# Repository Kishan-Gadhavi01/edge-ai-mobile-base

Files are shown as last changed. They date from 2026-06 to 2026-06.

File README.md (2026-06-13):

# Edge AI Mobile Base: VIO SLAM Subsystem

🟢 **System Status:** Active R&D / Phase 2 (Perception Optimization)

**The foundational mobility and spatial awareness module for an upcoming Embodied AI Mobile Manipulator. This independent subsystem utilizes ROS 2 Humble, NVIDIA Jetson, and an OAK-D Lite to achieve robust encoderless Visual-Inertial Odometry (VIO) and map generation.**

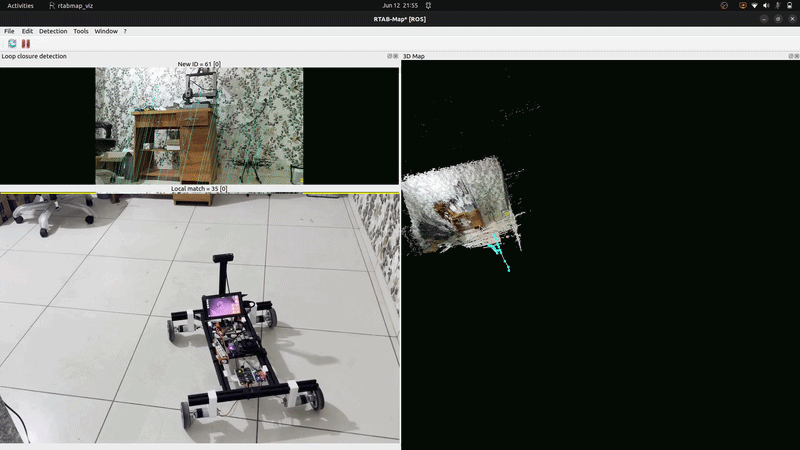
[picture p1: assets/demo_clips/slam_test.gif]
Chassis VIO SLAM Tracking


## 🧠 Modular Architecture Context

This repository houses the **Mobility and Perception Subsystem**. Operating as a fully independent Autonomous Mobile Robot (AMR) base, it is engineered with a strict **Distributed Middleware Architecture** to isolate real-time motor actuation from heavy spatial AI processing:

* **Actuation Layer (Low-Level):** An ESP32 microcontroller acting as a Hardware Abstraction Layer (HAL). It handles deterministic differential mixing and interfaces directly with Cytron motor drivers via a high-speed wireless UDP bridge.
* **Perception Layer (High-Level):** An NVIDIA edge compute node (Jetson) processing spatial depth maps and executing Visual-Inertial Odometry via ROS 2, eliminating the reliance on standard hardware wheel odometry.

---

## 📂 Repository Structure

```text
edge-ai-mobile-base/
├── cad/                        # 3D printable STL files and mechanical assembly diagrams
├── bom/
│   └── bom.md    # Component specs (motors, drivers, compute units)
├── esp_firmware/               # MicroPython code executed directly on the ESP32 HAL
│   ├── phase1_ap_mode/         # Standalone Wi-Fi Access Point execution script
│     └── main.py
│   └── phase2_client_mode/     # Distributed ROS 2 Subnet network execution script
│     └── main.py
├── host_controller/            # Python drive scripts executed on the Ubuntu Host Laptop
│   ├── phase1_manual/   
|     └──  robo_drive.py    
│   └── phase2_teleop/          # Routed subnet teleop mixing script (Subnet Client)
|     └── control.py    
├── ros2_nodes/                 # Perception stack executed directly on the NVIDIA Jetson
│   └── salm_ready.launch.py    # Custom VIO & RTAB-Map spatial mapping sequence
└── README.md                   # System overview & Deployment guide

```

---

## 🚀 Development Phases

### Phase 1: Hardware & Baseline Actuation - *Completed*

The foundational cycle focused entirely on verifying the physical chassis and ensuring deterministic, low-latency control before introducing AI overhead.

* **Mechanical & Electrical:** Designed custom 3D-printed mounting brackets for the Jetson and OAK-D. Integrated 12V motors and Cytron dual-channel drivers. *(See `/cad/` and `/bom/`)*
* **Wireless Teleoperation:** Engineered a high-speed MicroPython UDP server on the ESP32.
* **Kinematic Mixing:** Implemented a host-side teleoperation script to map standard Xbox controller axes into calculated differential PWM limits with strict deadzone filtering and emergency stop fallbacks.

### Phase 2: Embodied AI & Perception Integration - *Current*

Transitioning control from manual UDP teleoperation to an autonomous, middleware-driven ecosystem.

* **Middleware Integration:** Deployed ROS 2 Humble on the NVIDIA Jetson edge compute node.
* **Encoderless VIO SLAM:** Replaced physical wheel odometry with RTAB-Map's `rgbd_odometry` using the OAK-D Lite depth stream and internal IMU.
* **SLAM Resiliency Tuning:** Implemented custom parameter overrides (`Odom/GuessMotion: 'true'`, `Odom/ResetCountdown: '0'`) allowing the localization engine to predictive-coast during rapid yaw rotations to survive visual motion blur.
* **System-Level Optimization:** Tuned the Linux network kernel (`sysctl`) to expand packet fragmentation thresholds, stabilizing high-bandwidth point-cloud transmission.

---

## 🛠️ System Deployment & Replication Guide

Due to the distributed nature of this platform, setup and execution are split across the **ESP32 (Hardware Abstraction Layer)**, the **NVIDIA Jetson (Edge Node)**, and the **Ubuntu Host Laptop (Teleop & Visualization)**.

### Track 0: Actuation Firmware Installation (ESP32)

Before the AI middleware can communicate with the physical chassis, the ESP32 must be flashed with the correct network and kinematics firmware using the **Thonny IDE**.

1. **Select Operational Mode:**
* **Phase 1 (Standalone AP):** Use `esp_firmware/phase1_ap_mode/main.py`. The ESP32 hosts its own isolated Wi-Fi network. Best for raw teleop testing without a router.
* **Phase 2 (Subnet Client):** Use `esp_firmware/phase2_client_mode/main.py`. The ESP32 connects to your shared subnet (e.g., mobile hotspot) alongside the Jetson. **This is required for ROS 2 SLAM.**

2. **Configure Network:** Open the selected `main.py` in Thonny. If using Phase 2, update the hardcoded `SSID` and `PASSWORD` to match your host network.
3. **Flash:** Connect the ESP32 via USB, save `main.py` directly to the MicroPython device, and power cycle the chassis. The onboard LED will turn solid once the network and UDP listening socket (Port `12345`) are established.

---

### Track A: NVIDIA Jetson Setup (Perception Node)

**1. Base Dependencies & ROS 2 DepthAI Drivers**

```bash
sudo apt update && sudo apt upgrade -y
sudo apt install -y build-essential python3-dev htop nvtop gedit
sudo apt install -y libyaml-cpp-dev libarchive-dev libbz2-dev zlib1g-dev libcurl4-openssl-dev libprotobuf-dev protobuf-compiler liblzma-dev liblz4-dev
sudo apt install ros-humble-depthai-ros ros-humble-depth-image-proc ros-humble-rtabmap-launch -y
echo "source /opt/ros/humble/setup.bash" >> ~/.bashrc

```

**2. Deep Learning Environment Setup**
By default, NVIDIA Jetson platforms come pre-configured with TensorRT and CUDA bound to the native system Python.

*Standard Installation (Recommended):*
For the most stable experience, install the vision dependencies directly to your system:

```bash
pip3 install "numpy>=1.24,<2.0" opencv-python==4.9.0.80 tqdm pycuda

```

*Advanced Configuration (Conda Environments):*

> ⚠️ *Note: If you choose to use Miniconda to isolate your vision environment, Conda will break the native Jetson TensorRT and CUDA pathings. You must manually symlink the system libraries into your Conda environment.*

If you are using a Conda environment named `vision`, execute the following to restore hardware acceleration:

```bash
# 1. Install base dependencies inside Conda
conda install -c nvidia cuda-toolkit=12.4.1 cuda-version=12.4 cudnn -y
pip install "numpy>=1.24,<2.0" opencv-python==4.9.0.80 tqdm

# 2. Clean out conflicting conda libraries and link Jetson's native TensorRT bindings
rm -rf ~/miniconda3/envs/vision/lib/python3.10/site-packages/tensorrt*
rm -rf ~/miniconda3/envs/vision/lib/python3.10/site-packages/graphsurgeon*

ln -s /usr/lib/python3.10/dist-packages/tensorrt ~/miniconda3/envs/vision/lib/python3.10/site-packages/
ln -s /usr/lib/python3.10/dist-packages/graphsurgeon ~/miniconda3/envs/vision/lib/python3.10/site-packages/

# 3. Export explicit paths to your local CUDA compiler
export PATH=/usr/local/cuda-12.6/bin:$PATH
export LD_LIBRARY_PATH=/usr/lib/aarch64-linux-gnu:/usr/local/cuda-12.6/lib64:$LD_LIBRARY_PATH
export CUDA_ROOT=/usr/local/cuda-12.6

# 4. Force-compile PyCUDA from source against the localized compiler target
pip install pycuda --force-reinstall --no-binary :all:

```

**3. High-Throughput Kernel Tuning (Mandatory for Point Clouds)**
Execute this script to prevent ROS 2 node instability caused by UDP packet fragmentation over Wi-Fi:

```bash
sudo sysctl -w net.core.rmem_max=2147483647
sudo sysctl -w net.ipv4.ipfrag_time=3
sudo sysctl -w net.ipv4.ipfrag_high_thresh=134217728

```

---

### Track B: Ubuntu Host Laptop Setup (Teleop & Visualization)

**1. Teleoperation Environment**
Ensure an Xbox Controller is paired via Bluetooth to the laptop.

```bash
pip3 install pygame

```

**2. ROS 2 Visualization Dependencies**
The host laptop does not run the SLAM math, but it must be able to visualize the TF trees and point clouds generated by the Jetson.

```bash
sudo apt update
sudo apt install ros-humble-desktop ros-humble-rtabmap-viz -y
echo "source /opt/ros/humble/setup.bash" >> ~/.bashrc

```

---

## ⚡ Execution Sequence

To bring the entire Embodied AI platform online, execute these commands in the following sequence across your network:

**1. Initiate Teleoperation (Host Laptop)**

```bash
python3 host_controller/phase2_teleop/control.py

```

*(Use the Left Joystick to drive. The script manages raw kinematics and safety deadzones).*

**2. Initialize Vision Drivers (Jetson Terminal 1)**

```bash
ros2 launch depthai_ros_driver rgbd_pcl.launch.py 

```

**3. Launch Odometry & SLAM Engine (Jetson Terminal 2)**

```bash
rm -rf ~/.ros/rtabmap.db  # Clear stale mapping data
ros2 launch ros2_nodes/slam_ready.launch.py

```

**4. Remote Spatial Visualization (Host Laptop Terminal)**

```bash
ros2 run rtabmap_viz rtabmap_viz --ros-args -r rtabmap:=/rtabmap -r odom:=/rtabmap/odom

```

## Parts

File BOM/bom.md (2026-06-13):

### Bill of Materials (BOM)

| Phase | Qty | Component | Specification |
| --- | --- | --- | --- |
| **Phase 1** | 4 | Aluminum T-Slot Extrusions | 30x30 Profile 500mm |
| **Phase 1** | 4 | Cast Corner Brackets | EasyMech, for 30x30 Profile |
| **Phase 1** | 8 | Capped Allen Bolts & T-Nuts | M5, 11mm |
| **Phase 1** | 4 | Planetary Gear DC Motors | Pro-Range 12V, 185 RPM, 72.5 Ncm |
| **Phase 1** | 4 | Heavy Duty Disc Wheels | EasyMech 100mm, Gray |
| **Phase 1** | 4 | Anti-Slip Motor Couplings | EasyMech 8mm Internal Diameter (ID) |
| **Phase 1** | 1 | ESP32 Microcontroller | Hardware Abstraction Layer / Wi-Fi Subnet Client |
| **Phase 1** | 2 | Cytron MDD10A Motor Driver | Dual Channel Enhanced, 10A Continuous, 30A Peak |
| **Phase 1** | 1 | 3S LiPo Battery | Dedicated Drive Train Power |
| **Phase 1** | 1 | XL4015 DC-DC Stepdown Module | Adjustable Buck Converter (5A, 75W) with Digital Voltmeter (2x for pahse 2) |
| **Phase 1** | 2 | driver_support | 3D printed (petg prefferd) for cytron  |
| **Phase 1** | 4 | motor_mount | 3D printed (petg prefferd) |
| **Phase 1** | 1 | support | 3D printed (petg prefferd) |
| **Phase 2** | 1 | NVIDIA Jetson Orin Nano | Super Developer Kit (ROS 2 / SLAM Node) |
| **Phase 2** | 1 | Luxonis OAK-D Lite | Spatial Depth Camera with Autofocus |
| **Phase 2** | 1 | Waveshare HDMI LCD Display | 7-inch, 1024x600, Touch Screen with Case |
| **Phase 2** | 1 | 4S LiPo Battery | Pro-Range 14.8V, 5200mAh, 40C (Dedicated Compute Power) |
| **Phase 2** | 1 | XL4015 DC-DC Stepdown Module | Adjustable Buck Converter (5A, 75W) with Digital Voltmeter |

### Sites to procure items 
https://robu.in/

https://thinkrobotics.com/

https://tannatechbiz.com/

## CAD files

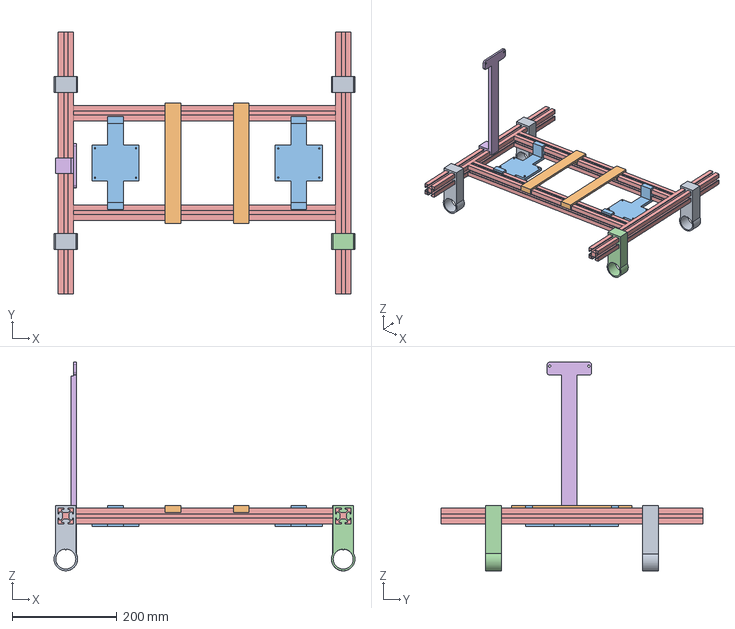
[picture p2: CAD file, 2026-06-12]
cad/Full_assembelly.step
575.0 x 500.0 x 399.0 mm

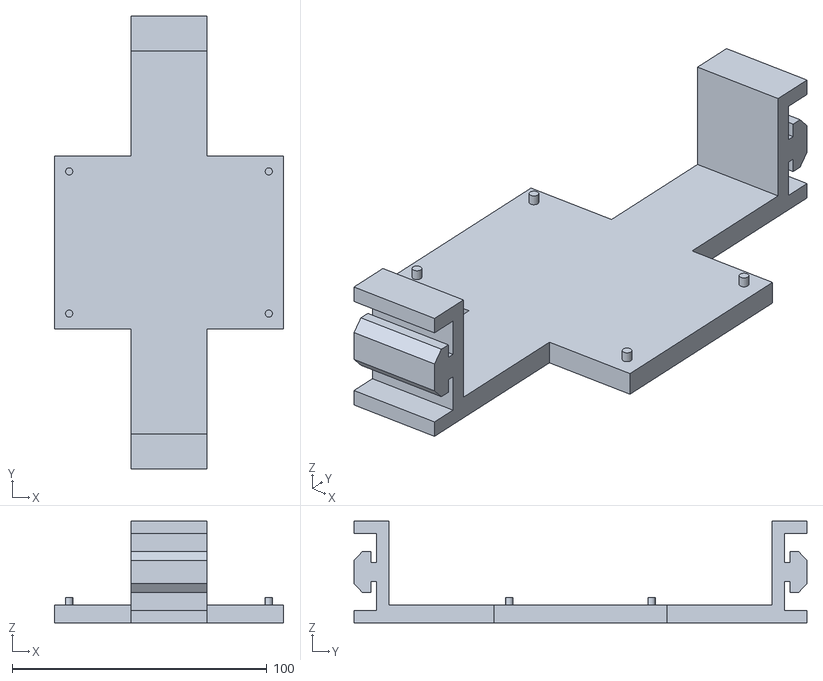
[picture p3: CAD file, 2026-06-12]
cad/driver_support.stl
90.0 x 177.7 x 40.0

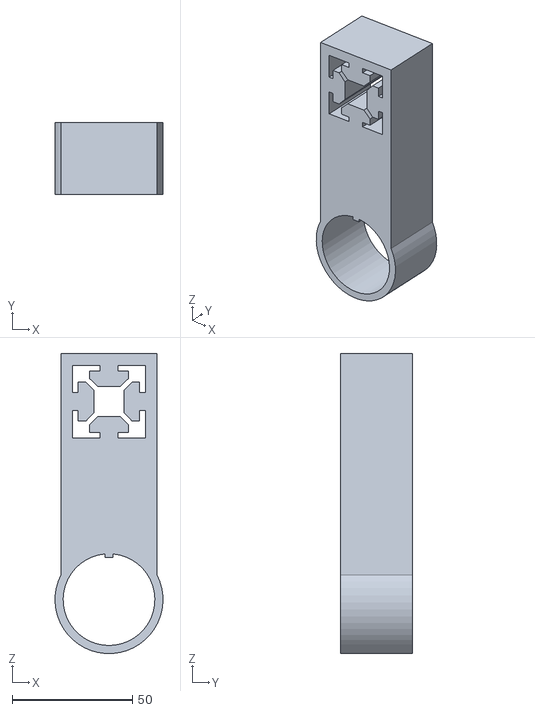
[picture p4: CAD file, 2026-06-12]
cad/motor_mount.stl
44.9 x 30.0 x 125.0

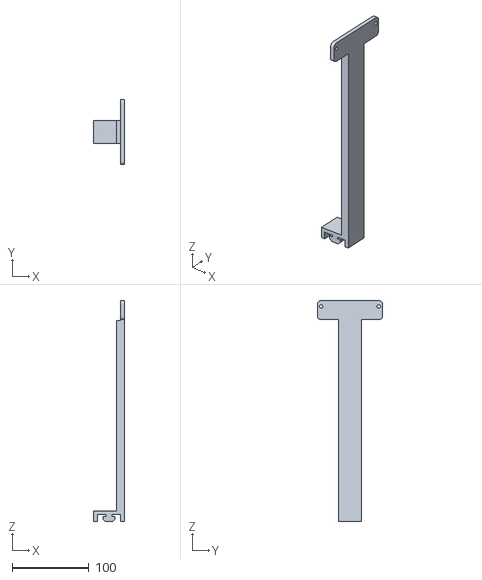
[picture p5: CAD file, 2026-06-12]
cad/camera_mount.stl
40.0 x 85.0 x 287.8

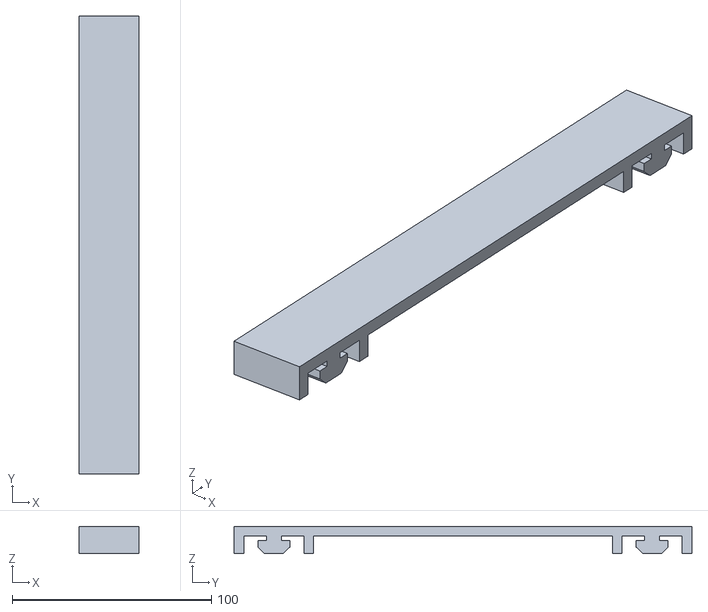
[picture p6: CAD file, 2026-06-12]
cad/support.stl
30.0 x 230.0 x 13.8

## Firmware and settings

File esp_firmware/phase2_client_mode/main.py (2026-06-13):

import network
import socket
import machine
import time

# --- Network Configuration ---
SSID = "Kishan's network "   # <-- CHANGE THIS TO YOUR SSID    
PASSWORD = "11223399" # <-- CHANGE THIS DUMMY PASSWORD
UDP_PORT = 12345
# --- 2. Hardware Safety & Pin Definitions (Axle-Split) ---
# 1kHz frequency is optimal for Cytron drivers
freq = 1000 
STATUS_LED = machine.Pin(2, machine.Pin.OUT, value=0)

# Board 1: Front Axle (Safety initialization: duty=0, value=0 instantly!)
pwm_fl = machine.PWM(machine.Pin(32), freq=freq, duty=0)
dir_fl = machine.Pin(33, machine.Pin.OUT, value=0)
pwm_fr = machine.PWM(machine.Pin(25), freq=freq, duty=0)
dir_fr = machine.Pin(21, machine.Pin.OUT, value=0)

# Board 2: Rear Axle
pwm_rl = machine.PWM(machine.Pin(26), freq=freq, duty=0)
dir_rl = machine.Pin(27, machine.Pin.OUT, value=0)
pwm_rr = machine.PWM(machine.Pin(14), freq=freq, duty=0)
dir_rr = machine.Pin(12, machine.Pin.OUT, value=0)

print("[+] Hardware initialized safely. Motors locked.")

# --- 3. Initialize Wi-Fi (Station Mode to iPhone) ---
wlan = network.WLAN(network.STA_IF)
wlan.active(True)

# --- FORCE STATIC IP FOR iPHONE HOTSPOT ---
# Format: (IP Address, Subnet Mask, Gateway, DNS)
wlan.ifconfig(('172.20.10.14', '255.255.255.240', '172.20.10.1', '8.8.8.8'))

# Clear out any crashed internal states before trying to connect
wlan.disconnect()
time.sleep(1) 

print(f"Connecting to {SSID}...")
wlan.connect(SSID, PASSWORD)

# Blink LED while connecting
led_state = 0
while not wlan.isconnected():
    led_state = 1 - led_state  
    STATUS_LED.value(led_state)
    time.sleep(0.5)            
    print('.', end='')

# Connection successful -> Turn LED solidly ON
STATUS_LED.value(1)
print('\n[+] Wi-Fi Connected!')
print('[!] The robot is permanently locked to IP: 172.20.10.14')

# --- 4. Initialize UDP Server ---
udp = socket.socket(socket.AF_INET, socket.SOCK_DGRAM)
udp.bind(("0.0.0.0", UDP_PORT))
udp.setblocking(False) 
print("UDP Server listening for controller input...\n")

# --- 5. Main Control Loop ---
while True:
    try:
        # Check for incoming wireless data
        data, addr = udp.recvfrom(255)
        msg = data.decode().strip()
        
        # Expected format from your laptop: <L:255,R:-255>
        if msg.startswith("<L:") and ">" in msg:
            core_string = msg[3:].split(">")[0]
            parts = core_string.split(",R:")
            
            if len(parts) == 2:
                left_speed = int(parts[0])
                right_speed = int(parts[1])
                
                # Scale laptop's 8-bit (255) resolution to ESP32's 10-bit (1023) resolution
                left_duty = min(1023, abs(left_speed) * 4)
                left_dir = 1 if left_speed >= 0 else 0
                
                right_duty = min(1023, abs(right_speed) * 4)
                right_dir = 1 if right_speed >= 0 else 0
                
                # --- EXECUTE LEFT WHEELS (Front Left & Rear Left) ---
                dir_fl.value(left_dir)
                dir_rl.value(left_dir)
                pwm_fl.duty(left_duty)
                pwm_rl.duty(left_duty)

                # --- EXECUTE RIGHT WHEELS (Front Right & Rear Right) ---
                dir_fr.value(right_dir)
                dir_rr.value(right_dir)
                pwm_fr.duty(right_duty)
                pwm_rr.duty(right_duty)

    except OSError:
        # No packet received this cycle, pass cleanly
        pass
    except ValueError:
        # Corrupted packet parsing error, ignore
        pass
        
    # --- The Breathing Valve ---
    # Prevents the loop from locking out Thonny/USB communications
    time.sleep(0.01)
